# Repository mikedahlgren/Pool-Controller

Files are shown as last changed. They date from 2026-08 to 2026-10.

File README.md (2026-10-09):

# Pool Controller

This runs a pool from a [Waveshare ESP32-S3-RELAY-6CH](https://www.waveshare.com/esp32-s3-relay-6ch.htm) and the PoolVeras sensor hat plugged onto its Pico headers.

The Waveshare board talks to the pump, switches the acid pump and the pool light, and reports its own chip temperature. The hat is where the sensors connect: Atlas probe circuits, a 4-20 mA filter-pressure sender, optional pH current loop, DS18B20 temperature sensors, and dry contacts. Home Assistant and the page at `http://pool-controller.local` show the readings. Once an hour the controller can post pH and water temperature to PoolVeras.

## How the hardware is split

| Job | Board |
|-----|---|
| Pentair IntelliFlo on RS485 | Waveshare, GPIO17 and GPIO18 |
| Acid pump | Waveshare relay CH2, GPIO2 |
| Pool light | Waveshare relay CH6, GPIO46 |
| Waterfall relay | Waveshare relay CH1, GPIO1. Leave it off unless you use it |
| Board temperature | Inside the ESP32-S3. This is the chip, not the pool |
| Atlas pH, ORP, salinity, RTD, or dissolved oxygen | Hat sockets. Any of those boards can go in any pair |
| Filter pressure and other 4-20 mA loops | Hat screw J8. Each loop needs its own 12 V or 24 V supply |
| Air and water temperature | Hat screw J6, DS18B20 sensors, one 4.7k shunt on JP6 |
| Dry contacts | Hat screw J7. A bare switch to the GND screw. ON means closed |

CH3, CH4, and CH5 on the Waveshare are free. The hat's 3.3 V rail, through fuse F1, powers the Atlas boards and the 1-Wire sensors. It does not power the 4-20 mA loops.

Screw order on the hat, left to right, is J3 through J8. Probe returns land on PGND next to PRB, not on the board ground screws.

Connector-by-connector wiring is in [esphome/README.md](esphome/README.md). Acid dosing is in [esphome/ACID_PH.md](esphome/ACID_PH.md). Filter pressure is in [esphome/FILTER_PRESSURE.md](esphome/FILTER_PRESSURE.md). The board files are in [hardware/sensor-hat](hardware/sensor-hat).

## Install

Use ESPHome 2025.9.0 or newer.

From Home Assistant, paste [`esphome/ha-pool-controller.yaml`](esphome/ha-pool-controller.yaml) into ESPHome Builder. It loads the rest of the firmware from the `PoolverasV1` branch. Copy the keys in [`esphome/secrets.yaml.example`](esphome/secrets.yaml.example) into Home Assistant's `secrets.yaml`, then Install.

From a clone of this repo:

```bash
esphome run esphome/pool-controller.yaml
```

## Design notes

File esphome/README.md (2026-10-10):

# Sensor hat

The hat plugs onto the Waveshare Pico headers. Screw connectors run along the edge, left to right: **J3, J4, J5, J6, J7, J8**.

Relays and the pump cable stay on the Waveshare. See [the repo README](../README.md).

## Atlas circuit boards

Three pairs of sockets. The silk says pH, ORP, and EZO so the installer can tell them apart. Any Atlas circuit can go in any pair: pH, ORP, conductivity (salinity), RTD, or dissolved oxygen.

Each circuit uses both sockets in its pair.

- The socket nearer the screws is power: VCC, PRB, PGND.
- The socket farther from the screws is data: GND, TX, RX. Pin 1 of that socket is ground.

The probe cable lands on the two screws under that pair.

| Pair | Screws | Probe screws, left to right |
|---|---|---|
| Labeled pH | J3 | PRB, PGND |
| Labeled ORP | J4 | PRB, PGND |
| Labeled EZO | J5 | PRB, PGND |

PRB is the probe signal. PGND is that probe's return. PGND is not the ground screw on J6 or J7. Leave the probe return on PGND.

Factory boards on the pairs labeled pH and ORP speak UART and answer as soon as they are seated. The device page shows what each socket found: pH Socket, ORP Socket, EZO Socket. Readings show up as EZO pH, ORP, Conductivity, Salinity, TDS, RTD Temperature, or Dissolved Oxygen, based on the board, not the label.

A board that was already switched to I2C still works in any socket. Two of the same type: the reading comes from the first socket that has one, in the order pH label, ORP label, EZO label.

The third pair (labeled EZO) is the I2C bus, shared with J16. J16 is a female 4-pin socket for a 2.42 inch SSD1309. Pin order, from the left: GND, 3V3, SCL, SDA. The screen address is 0x3C. Solder the socket and plug the display in with its GND pin on the left. A factory UART board on that pair will fight the screen, so switch that Atlas board to I2C on one of the other pairs first. Atlas defaults are 99 (pH), 98 (ORP), and 100 (EC).

## pH

Pool pH is the value used for acid dosing and PoolVeras. On the device page, **pH Source** chooses it:

| Setting | What Pool pH uses |
|---|---|
| Auto | The Atlas pH board, if one is answering. Otherwise the 4-20 mA kit. |
| EZO | The Atlas pH board only. |
| 4-20 mA | The industrial kit on J8 screw 2 only. |

`ph_offset` trims only the 4-20 mA reading. Calibrate an Atlas pH board on the module.

Acid dosing behavior is in [ACID_PH.md](ACID_PH.md).

## 4-20 mA (J8)

Left to right: GND, 1, 2, 3, 4.

Each signal screw already has a 150 ohm resistor to the GND screw, plus a filter and a clamp. Do not add another shunt.

These loops need their own DC supply, usually 12 V or 24 V, inside the transmitter's range. Do not power them from the hat's 3.3 V pin.

For each channel:

1. Supply positive to the transmitter positive.
2. Transmitter negative to that channel's signal screw.
3. Supply negative to the GND screw.

One supply can feed all four channels. Split the positive side. Each transmitter returns on its own signal screw.

| Screw | What the firmware does |
|---|---|
| 1 | Filter pressure. GPIO7. Default range 0 to 0.5 MPa. See [FILTER_PRESSURE.md](FILTER_PRESSURE.md). |
| 2 | Industrial pH kit, 4 mA = 0 pH, 20 mA = 14 pH. GPIO8. |
| 3 | Milliamps only. GPIO9. |
| 4 | Milliamps only. GPIO10. |

At 20 mA the 150 ohm resistor is 3.0 V. The ESP32-S3 analog input is soft above about 2.5 V, which is about 16 mA. Normal pool pressure and pH sit under that. The top of the scale reads a little low. The 150 ohm parts stay as they are.

Do not land a fault wire from the Atlas industrial transmitter on the hat. That output is 12 to 24 V.

## 1-Wire (J6)

Left to right: 3V3, DATA, GND. The data pin is GPIO37.

This is for DS18B20 sensors. Air and water can share the three screws. Fit **one** shunt on JP6. Use the 4.7k position for these sensors. The 2.2k and 1k positions are the other choices. Do not fit more than one.

After the first boot, copy each sensor's address from the ESPHome log into `secrets.yaml` as `air_temp_id` and `water_temp_id`.

**Board Temperature** is separate. It is the ESP32-S3 chip, in °F. It rises when WiFi is busy. It is not a stand-in for the air or water sensor.

## Contacts (J7)

Left to right: GND, 1, 2, 3, 4.

Each input is a dry contact: a switch with no voltage of its own. One side goes to a numbered screw. The other side goes to the GND screw on J7. ON means that switch is closed.

| Screw | GPIO |
|---|---|
| 1 | GPIO47 |
| 2 | GPIO16 |
| 3 | GPIO14 |
| 4 | GPIO13 |

Do not connect a powered switch output (5 V, 12 V, or 24 V). The clamp will hold the pin in a safe range and dump the extra current onto the 3.3 V rail.

## Power on the hat

The hat takes 3.3 V from the Waveshare header, through fuse F1 (0.2 A). That rail runs the Atlas circuits, the 1-Wire sensors, and the pull-ups. It does not run 4-20 mA loops.

## Install

Home Assistant: paste [`ha-pool-controller.yaml`](ha-pool-controller.yaml) into ESPHome Builder. It loads the packages from the `PoolverasV1` branch. Add the keys in [`secrets.yaml.example`](secrets.yaml.example) to Home Assistant's `secrets.yaml`, then Install.

From a clone, at the repo root:

```bash
esphome run esphome/pool-controller.yaml
```

The device page is `http://pool-controller.local`.

ESPHome 2025.9.0 or newer. The custom pieces are `pentair_if_ic` (the pump) and `atlas_ezo` (the three sockets).

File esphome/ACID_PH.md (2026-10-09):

# pH probe and Stenner 45M5 acid dosing

For a **50,000 gallon** pool with **31% muriatic acid** and a **Stenner 45M5** (120 V, 1.7 A, #5 tube, **2.5–50 GPD** depending on the dial).

Pool pH can come from an Atlas pH circuit in any socket, or from the industrial 4-20 mA kit on J8 screw 2. **pH Source** on the device page picks which one. Auto uses the circuit board when it answers, and the kit otherwise. Connector map: [README.md](README.md).

The kit is the [Atlas Scientific Industrial pH Kit](https://atlas-scientific.com/kits/industrial-ph-kit/) (KIT-102P): 4 mA is 0 pH, 20 mA is 14 pH. The 150 ohm shunt for that screw is already on the hat. `ph_offset` trims the kit reading only.

Lights stay on **CH6**. Acid uses **CH2**. Do **not** put the Stenner on CH1 — that GPIO still belongs to the unused waterfall switch in `schedule.yaml`. Leave **Waterfall (Auto) OFF** in Home Assistant so CH1 does not chatter.

## Relays on the Waveshare ESP32-S3-RELAY-6CH

| Channel | GPIO | Use |
|---|---|-----|
| CH1 | GPIO1 | Unused (waterfall YAML — leave off) |
| **CH2** | **GPIO2** | **Stenner 45M5 hot** |
| CH6 | GPIO46 | Pool lights (existing) |

## Stenner electrical (CH2)

Switch **only the 120 V hot**. Neutral and ground stay continuous.

```
Panel 120 V hot ──> CH2 COM
CH2 NO ────────────> Stenner black (hot)
Stenner white ─────> Neutral
Stenner green ─────> Ground
```

1.7 A is well under the 10 A relay. Add an **RC snubber** (or MOV) across the Stenner motor leads if the relay pits or Wi‑Fi blips when it clicks — it is an inductive motor.

`restore_mode` is always off. Home Assistant cannot leave the pump on; only a timed pulse script can energize it. A 1-second watchdog force-offs if that fails.

## Plumbing (25 PSI max)

The 45M5 is rated **25 PSI**. Inject into the **return after the filter** (and after a heater if you have one), never into the filter inlet / head-pressure port, and **never into the pH sample loop** (that stream returns to pump suction).

Keep the injection check valve. Prime suction from the acid tank with the pump running using **Acid Prime 10s**.

## Stenner dial

At **100%** the 45M5 is about **4.4 fl oz/min** — too fast to hold on for a 50k pool. Set the mechanical dial to about **20–30%** (~10–15 GPD, ~0.9–1.3 oz/min), then let the ESP pulse.

Default firmware pulse is **10 seconds**, then **15 minutes** settle, max **1200 s (20 min) per calendar day**. Measure actual output with a graduated cylinder (tube wear and dial both matter).

Rough chemistry (31% HCl, 50,000 gal, typical TA): on the order of **tens of ounces** to move pH ~0.2. That is many 10 s pulses over hours, which is the point — no single dump.

## Atlas Industrial pH Kit (KIT-102P)

| In the kit | Role |
|---|---|
| Industrial pH Transmitter (IND-pH) | Isolated **4-wire** transmitter: 9–36 VDC power, **4–20 mA = 0–14 pH**, 35 mm DIN rail, local display and buttons |
| Industrial pH probe | 3/4″ NPT body, ~10 ft cable, double-junction. Order **with PT-1000** so the transmitter can temperature-compensate |
| pH 4 / 7 / 10 pouches + storage pouch | First calibration only; buy bottles for later |

Do **not** wire the glass probe to the ESP32. The transmitter does the high-impedance work; the ESP only reads the 4–20 mA loop.

This is **not** the Yosoo filter-pressure wiring. Yosoo is a 2-wire loop (power and signal are the same pair). Atlas is **4-wire**: power on one pair, isolated 4–20 mA on another.

### Extra parts (not in the kit)

| Item | Notes |
|---|---|
| **Second** 150 Ω 1% metal-film, ≥0.25 W | Dedicated shunt. Do not share the filter-pressure resistor. **Not 250 Ω** (20 mA × 250 Ω = 5 V, above the ESP32 ADC). |
| 35 mm DIN-rail snippet | Transmitter is DIN-rail only and is **not** weatherproof. Mount it dry next to the Waveshare board. |
| 1″ × 3/4″ FNPT tee (or 1″ tee + 3/4″ bushing) | Probe is 3/4″ NPT. Atlas’s cheap lab “probe pipe fitting” is the wrong body. |
| Isolation ball valves on the sample loop | Close them **full of water** for calibration or to keep the glass wet. |
| PTFE tape | 3/4″ NPT into the tee. Keep tape off the flat sensing face. |

Board **VIN must be 12–24 V DC** (same supply as the Yosoo). USB 5 V will not run this transmitter (it needs 9–36 V). Atlas minimum is 9 V; 12 V is the practical floor with the pressure loop.

### Probe plumbing (1″ sample loop)

Reuse the old discharge-to-suction 1″ PVC cell:

- Takeoff **after the pump**, return **before the pump**. After-filter takeoff is cleaner if the piping can move; after the CircuPool cell is worse (gas / high chlorine on the glass).
- Probe in a **1″ × 3/4″ FNPT** tee. Water should sweep the flat face (slight angle or vertical). Not upside down (gel void). Not in a dead-end trap.
- Keep the cell a **low wet pocket** so it cannot drain when the IntelliFlo stops. A light check on the suction return is optional; a U-bend is more reliable than stiff spring checks (those can stall at Speed 1).
- Leave sample valves **open** in normal use. RPM interlocks prove the IntelliFlo is running, not that this bypass is open.
- If you blow the lines for winter, **pull the probe** into storage solution.

### Transmitter terminals

Connect only **power**, **pH probe**, **PT-1000** (if present), and **4–20 mA**. Leave the rest disconnected.

| Terminal | Connect to | Notes |
|---|---|---|
| **PWR + / PWR −** (larger keyed plug, 9–36 V) | Board **VIN+** / **VIN−** | Separate from the 4–20 mA pair |
| **pH** (two wires) | Probe pH pair | Reverse does not damage the probe; readings will be wrong |
| **TEMP** (two wires) | Probe PT-1000 | No polarity |
| **4–20 mA + / −** | J8 screw 2 and the GND screw | Isolated current. 4 mA = 0 pH, 20 mA = 14 pH. The shunt is on the hat. |
| **F** (fault) | **Nothing** | Outputs **12–24 V** (same as PWR). Will destroy an ESP GPIO |
| **4 / 7 / 10** (PLC cal) | **Nothing** | Optional PLC strobes; calibrate with the buttons instead |

### 4-20 mA wiring (J8 screw 2)

Power the transmitter from 12 V or 24 V, not from the hat's 3.3 V. Filter pressure, if you use it, takes J8 screw 1. Do not share the two signal screws.

```
Supply +  ---- transmitter PWR +
Supply -  ---- transmitter PWR -  and J8 GND

transmitter 4-20 mA +  ---- J8 screw 2
transmitter 4-20 mA -  ---- J8 GND
```

At 150 ohm: 4 mA is 0.60 V (pH 0), 12 mA is 1.80 V (pH 7), 20 mA is 3.00 V (pH 14). The analog input is soft above about 2.5 V, so a reading near 14 pH can sit a little low. Normal pool pH does not.

ESP32 ADC max is about 3.1 V at 12 dB attenuation, so 3.00 V at pH 14 is intentional headroom. **pH Loop Current** and **pH Loop Voltage** on the device page are the diagnostics.

Below ~3.5 mA or above ~21 mA the firmware publishes `Pool pH` as unknown (open wire / short) and **Acid Interlock** shows a probe fault.

### Substitutions (`ha-pool-controller.yaml` / `pool-controller.yaml`)

These values are for KIT-102P. Do not change the pH scale unless you replace the transmitter.

```yaml
acid_pump_pin: GPIO2
ph_sensor_pin: GPIO8
ph_shunt_ohms: "150.0"
ph_scale_low: "0"
ph_scale_high: "14"
ph_offset: "0.2"    # added to the 4–20 mA scale so ESP/HA match the Atlas display
ph_update_interval: "5s"  # Pool pH, loop voltage, and loop current
acid_pump_gpd: "25"       # Stenner GPD at dial 10 (this install is a 25 GPD pump)
```

### Calibrate on the transmitter, then trim the loop

The ESP does not store pH calibration. Buffers are done **on the Atlas** (display / buttons). **CAL 7 first** — that resets stored points; then 4 and 10.

1. Probe in pH 7. Hold the **orange** button ~1.5 s (`CAL7` → `donE`).
2. Rinse, pH 4, **red** button. Optional pH 10, **blue** button.
3. Trim 4–20 mA so Home Assistant matches: hold **red + blue** ~1.5 s. Adjust 20 mA until **Pool pH** just hits 14.000, save; then 4 mA until 0.000. Use **pH Loop Current** as a check (pH 7 buffer → 12.00 mA).
4. If the ESP page / Home Assistant still sit a fixed amount away from the Atlas display (ADC and shunt error), set `ph_offset` in `ha-pool-controller.yaml` (default `0.2`, added to the 4–20 mA value) and reflash. Do not change `ph_scale_low` / `ph_scale_high`.

A two-point 7 then 4 is enough for a pool. The kit pouches are one first cal; keep bottles of 7 and 4 on the pad.

## Interlocks (auto and Acid Pulse)

All must pass:

- IntelliFlo running and RPM ≥ **Acid Min Pump RPM** (default 1200)
- pH between **6.8 and 8.6** (probe in water, not failed)
- pH not already below **7.1**
- Today’s runtime under **Acid Max Seconds Today**
- After a pulse, wait **Acid Settle Minutes**

**Acid Auto Dose** uses hysteresis: a correction starts when pH ≥ **Acid pH Start** (default 7.6) and keeps pulsing until pH ≤ **Acid pH Target** (7.4). Auto does **not** come back on after a reboot — you have to enable it again.

**Acid Prime 10s** only requires the circulation pump at min RPM (for filling tubing).

Until the pH loop reads ~4–20 mA, **Acid Interlock** is not `OK` and auto-dose will not run.

## First-week checkout

1. Wire CH2 and confirm **Acid Prime** with a bucket on the discharge (pump on, auto **off**).
2. Power the Atlas from VIN (display on). Confirm **pH Loop Current** is in the 4–20 mA range with the probe in water.
3. Calibrate 7 then 4 on the transmitter; confirm Home Assistant **Pool pH** against the buffers, then a Taylor test of the pool.
4. Leave **Acid Auto Dose off**. Use one **Acid Pulse** and watch pH over 30+ minutes.
5. Enable auto only after a pulse matches a Taylor/FAS-DPD sanity check.

Turn auto **off** when vacuuming, backwashing, or working on the pad.

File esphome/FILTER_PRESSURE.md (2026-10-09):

# Filter tank head-pressure sensor

This adds filter-tank pressure measurement to the Waveshare **ESP32-S3-RELAY-6CH** using a 2-wire **4–20 mA** transmitter such as:

[Yosoo Silicon Pressure Transmitter, 4–20 mA, G1/4, 0–0.5 MPa (ASIN B07NQ36XTC)](https://www.amazon.com/gp/product/B07NQ36XTC)

The IntelliFlo `Pressure` entity already in Home Assistant is the **pump’s internal reading** (bar). This package is a separate gauge on the **filter tank** so you can see when the cartridge/sand needs cleaning.

## Sensor specs (this listing)

| Item | Value |
|---|---|
| Output | 4–20 mA (loop-powered, typically 2-wire) |
| Range | 0–0.5 MPa (0–5 bar, **0–72.5 psi**) |
| Supply | **8–32 V DC** (do not power from 5 V USB or 3.3 V) |
| Thread | **G1/4** (BSPP, not NPT) |
| Media | Water, air, oil (stainless body) |

Pool sand/cartridge filters usually run in the **8–25 psi** range, so 0–0.5 MPa is a good fit.

The hat already has the 150 ohm shunt, the filter capacitor, and the clamp. Connector map: [README.md](README.md).

## Wiring

J8, left to right: GND, 1, 2, 3, 4. Filter pressure is screw 1 (GPIO7).

Use a separate 12 V or 24 V supply. Do not use the hat's 3.3 V, and do not use the RS485 ground.

```
Supply +  ---- transmitter +
Transmitter - ---- J8 screw 1
Supply -  ---- J8 GND screw
```

A 3-wire unit uses the same GND screw for its ground wire, and screw 1 for the signal.

At 150 ohm: 4 mA is 0.60 V (0 psi), 12 mA is 1.80 V, 20 mA is 3.00 V (72.5 psi). The analog input is soft above about 2.5 V, so the top of the scale reads a little low. Normal filter pressure sits under that.

Plumbing parts that are not on the hat: a G1/4 to 1/4 inch NPT adapter if the filter port is NPT, a tee if you want to keep the mechanical gauge, and PTFE tape. The Yosoo thread is G1/4.

## Plumbing

1. Kill power to the pump. Isolate and depressurize the filter (open the air relief / drain as your filter manual describes).
2. Remove the mechanical gauge, or install a **tee** so the gauge stays.
3. Fit the G1/4 → NPT adapter if needed. Do not crank a stainless G1/4 sensor hard into a plastic NPT port.
4. Mount the transmitter **upright** if the body has a cable gland, with the cable dripping down so water does not run into the connector.
5. Restart the pump and check for leaks **before** sealing the electrical box.

## Firmware substitutions

In `esphome/pool-controller.yaml`:

```yaml
substitutions:
  filter_pressure_pin: GPIO7
  filter_pressure_shunt_ohms: "150.0"
  filter_pressure_full_scale_mpa: "0.5"
```

If you bought a different Yosoo range (0–0.2 / 1.0 / 1.6 MPa), change `filter_pressure_full_scale_mpa` to match the label on the sensor.

If you use a different shunt (120 Ω is also safe), set `filter_pressure_shunt_ohms` to that value. Stay at or below **150 Ω** so 20 mA cannot exceed ~3.1 V.

## Entities

| Entity | Purpose |
|---|---|
| **Filter Tank Pressure** | Head pressure in psi |
| **Filter Tank Pressure Bar** | Same reading in bar (compare to IntelliFlo pressure) |
| **Filter Loop Current** | Diagnostic mA; ~4 mA at rest, ~8–16 mA while the pump is on |
| **Filter Pressure Voltage** | Raw ADC volts |
| **Filter Clean Speed 1–4** | Learned (or manually set) clean-filter psi at that speed. 0 = not learned yet |
| **Filter Est Speed 1–4** | Effective clean psi: learned value if present, otherwise estimated from other speeds |
| **Filter Clean Baseline** | Clean psi used right now |
| **Filter Pressure Over Clean** | Current psi minus baseline. Backwash when this reaches **Filter Pressure Rise** |
| **Filter Pressure Rise** | Trip delta (default **10 psi**, Pentair Triton II) |
| **Filter Learn Hours** | How long a speed must run before a baseline is learned (default **2**, max 48) |
| **Filter Learn Time** | Hours of Speed 1–4 runtime collected toward the current learn window |
| **Filter Needs Backwash** | Problem binary sensor (stays on after the pump stops) |
| **Filter Backwash Detail** | Why it is or is not calling for a backwash |
| **Filter Pressure Fault** | Loop &lt; 3.5 mA (open) or &gt; 21 mA (short) |
| **Save Clean Filter Pressure** | Optional: store the current reading now instead of waiting to learn |
| **Reset Filter Baselines** | Clear learned values and start over (sand change, etc.) |

Pentair’s Triton II TR140 manual: backwash at **+10 psi** over the clean reading. Leave rise at 10.

### How baselines are learned

You do **not** have to press Save. Example: Speed 1 at 1500 RPM, lowest 2-hour average is 8 psi → **Filter Clean Speed 1** becomes 8 psi → trip at **18 psi**.

The firmware:

1. Ignores the first 10 minutes after the IntelliFlo starts (air purge / prime).
2. While RPM is within ~200 of Speed 1–4, records 5-minute averages.
3. After **Filter Learn Hours** of that speed’s runtime (default 2, not necessarily one continuous wall-clock block), takes the **lowest** N-hour average seen.
4. Only **lowers** a baseline after that (a dirty week cannot raise the clean number). After a backwash, a lower stretch updates it.
5. Speeds you have not run yet are estimated from the ones you have (`head ≈ a + b·RPM²`).

Set **Filter Learn Hours** to 4 or 8 if you want a longer, more conservative window. Save is still there if you just backwashed and do not want to wait. **Reset Filter Baselines** after new sand.

The backwash flag only **updates** while the pump is running near a known speed. If it trips, it **stays on** after the pump shuts off so Home Assistant can still notify you at night.

## Checkout

1. Power the Waveshare board from **12–24 V** on the VIN screw terminal (not USB alone).
2. With the transmitter disconnected, Filter Loop Current should drop and **Filter Pressure Fault** should turn on.
3. With the transmitter connected and the pump **off**, expect roughly **4 mA / ~0 psi** (plus a little gauge offset).
4. Start the pump; pressure should rise into the same ballpark as the mechanical gauge (often within 1–2 psi; cheap transmitters are about ±1.5% FS).
5. If the reading is stuck near 0 or the fault stays on, swap red/black — a reversed 2-wire loop reads as an open circuit.

## Home Assistant

After the ESPHome API reconnects you should see `sensor.filter_tank_pressure` and `binary_sensor.filter_needs_backwash` (`device_class: problem`). A simple notify:

```yaml
automation:
  - alias: Pool filter needs backwash
    trigger:
      - platform: state
        entity_id: binary_sensor.pool_controller_filter_needs_backwash
        to: "on"
    action:
      - service: notify.mobile_app_your_phone
        data:
          title: Pool filter
          message: "TR140 is about +10 psi over clean. Time to backwash."
```

Replace the entity_id and notify target with the names Home Assistant actually assigned. You can also put **Filter Needs Backwash** on a dashboard badge and skip the automation until you want a push.

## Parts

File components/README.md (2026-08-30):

# ESPHome Components

## [pentair_if_ic](pentair_if_ic/README.md)

Controls a Pentair IntelliFlo variable-speed pump over RS485, and optionally a Pentair IntelliChlor on the same bus.

- Shared RS485 with bus arbitration
- Pump sensors and controls for Home Assistant
- IntelliChlor package is optional (`esphome/Include/chlorinator.yaml`); this install uses a CircuPool cell that does not speak that protocol

Home Assistant ESPHome Builder loads this from GitHub via `esphome/ha-pool-controller.yaml`. A local CLI compile uses `external_components` in `esphome/pool-controller.yaml`.

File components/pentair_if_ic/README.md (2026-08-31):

# Pentair IntelliFlo + IntelliChlor Component

ESPHome component for controlling Pentair IntelliFlo variable speed pumps and IntelliChlor salt water chlorinators over RS485.
This component is a combination of two other components:
1. [Nicostrown's Pentair Intelliflo Component](https://github.com/nicostrown/ESPHome-Pentair-Intelliflo) with a fix to the RPM setting protocal and adding mor information from the staus request.
2. [Scott Wolf's (wolfson292) Pentair Intellichlor component](https://github.com/wolfson292/intellichlor)

The major change is they both use the same in and out buffers, so the pump and clorinator can communicate on a common RS485 bus.

## Features

- **Unified Communication**: Single component manages both IntelliFlo pump and IntelliChlor chlorinator on shared RS485 bus
- **Automatic Polling**: Configurable polling intervals (default 30s)
- **Bus Arbitration**: Prevents transmission collisions between protocols
- **Full Sensor Support**: Exposes all known pump and chlorinator sensors to Home Assistant
- **Manual Refresh**: On-demand chlorinator status updates via button/automation

## Hardware Requirements

- ESP32 or ESP8266
- RS485 to TTL converter (e.g., MAX485) if not part of your board
- Pentair IntelliFlo pump
- Pentair IntelliChlor chlorinator
- Optional: Flow control pin for half-duplex RS485

## Installation

Add to your ESPHome configuration:

```yaml
external_components:
  - source: components/Pool_Automation/components
    components: [pentair_if_ic]
    refresh: 0s

uart:
  - id: uart_bus
    tx_pin: GPIO17
    rx_pin: GPIO16
    baud_rate: 9600

pentair_if_ic:
  id: my_pentair
  uart_id: uart_bus
  update_interval: 30s
  # Optional: poll IntelliChlor on this bus (default true). CircuPool / no SWG: false
  # enable_intellichlor: false
  # Optional: flow_control_pin for RS485 direction control
  # flow_control_pin: GPIO4
```

## Configuration Variables

### Platform Configuration

- **id** (*Required*, ID): Unique ID for the component instance
- **uart_id** (*Required*, ID): ID of the UART bus
- **update_interval** (*Optional*, Time): Polling interval (default: 30s)
- **enable_intellichlor** (*Optional*, boolean): Queue IntelliChlor commands on the shared RS485 bus (default: `true`). Set `false` if the only device on the bus is an IntelliFlo (this install: CircuPool RJ-60 PLUS).
- **flow_control_pin** (*Optional*, Pin): GPIO pin for RS485 direction control

### IntelliFlo Pump Sensors

```yaml
sensor:
  - platform: pentair_if_ic
    power:
      name: "Pump Power"
      id: pump_power
      unit_of_measurement: "W"
    rpm:
      name: "Pump RPM"
      id: pump_rpm
      unit_of_measurement: "RPM"
    flow:
      name: "Pump Flow Rate"
      id: pump_flow
      unit_of_measurement: "GPM"
    pressure:
      name: "Pump Pressure"
      id: pump_pressure
      unit_of_measurement: "PSI"
    time_remaining:
      name: "Program Time Remaining"
      id: time_remaining
      unit_of_measurement: "min"
    clock:
      name: "Pump Clock"
      id: pump_clock
      unit_of_measurement: "min"

binary_sensor:
  - platform: pentair_if_ic
    running:
      name: "Pump Running"
      id: pump_running

text_sensor:
  - platform: pentair_if_ic
    program:
      name: "Active Program"
      id: active_program
```

### IntelliChlor Sensors

```yaml
sensor:
  - platform: pentair_if_ic
    salt_ppm:
      name: "Salt Level"
      id: salt_ppm
      unit_of_measurement: "PPM"
    water_temp:
      name: "Water Temperature"
      id: water_temp
      unit_of_measurement: "°F"
    status:
      name: "Chlorinator Status"
      id: chlorinator_status
    error:
      name: "Chlorinator Error"
      id: chlorinator_error
    set_percent:
      name: "Chlorinator Output %"
      id: chlorinator_set_percent
      unit_of_measurement: "%"

binary_sensor:
  - platform: pentair_if_ic
    no_flow:
      name: "No Flow Alarm"
    low_salt:
      name: "Low Salt Alarm"
    high_salt:
      name: "High Salt Alarm"
    clean:
      name: "Clean Cell Required"
    high_current:
      name: "High Current Alarm"
    low_volts:
      name: "Low Voltage Alarm"
    low_temp:
      name: "Low Temperature Alarm"
    check_pcb:
      name: "Check PCB"

text_sensor:
  - platform: pentair_if_ic
    version:
      name: "Chlorinator Version"
      id: chlorinator_version

number:
  - platform: pentair_if_ic
    swg_percent:
      name: "Chlorine Output"
      id: swg_percent_number
      min_value: 0
      max_value: 100
      step: 1

switch:
  - platform: pentair_if_ic
    takeover_mode:
      name: "Takeover Mode"
      id: takeover_mode_switch
```

## Available Functions

Call these functions from Lambda actions or automations:

### Pump Control Functions

```cpp
// Request current pump status
id(my_pentair).requestPumpStatus();

// Start/stop pump
id(my_pentair).run();
id(my_pentair).stop();

// Set pump to specific RPM
id(my_pentair).commandRPM(1450);  // RPM value

// Set pump to specific flow rate
id(my_pentair).commandFlow(45);  // Flow in GPM * 10

// Run local program (1-4)
id(my_pentair).commandLocalProgram(0);  // Program 1
id(my_pentair).commandLocalProgram(1);  // Program 2

// Run external program (1-4)
id(my_pentair).commandExternalProgram(0);  // External Program 1

// Save RPM value to program slot
id(my_pentair).saveValueForProgram(0, 1450);  // Program 1, 1450 RPM

// Control modes
id(my_pentair).pumpToLocalControl();
id(my_pentair).pumpToRemoteControl();

// Set pump clock (NOTE: Not supported on most IntelliFlo models)
// Most pumps return error 0xFF 0x19 - clock is read-only
// Clock must be set via pump's physical keypad on most models
id(my_pentair).setPumpClock(14, 30);  // Set to 14:30 (2:30 PM)
```

### Chlorinator Control Functions

```cpp
// Refresh chlorinator status (bypasses rate limiting)
id(my_pentair).refresh_chlorinator();

// Standard refresh (respects 25s rate limit)
id(my_pentair).read_all_chlorinator_info();

// Legacy alias
id(my_pentair).read_all_info();
```

## Example Configurations

### Complete Pool Controller

```yaml
external_components:
  - source: components/Pool_Automation/components
    components: [pentair_if_ic]
    refresh: 0s

uart:
  - id: uart_bus
    tx_pin: GPIO17
    rx_pin: GPIO16
    baud_rate: 9600

pentair_if_ic:
  id: my_pentair
  uart_id: uart_bus
  update_interval: 30s

sensor:
  - platform: pentair_if_ic
    power:
      name: "Pool Pump Power"
    rpm:
      name: "Pool Pump RPM"
    salt_ppm:
      name: "Pool Salt Level"
    water_temp:
      name: "Pool Water Temperature"

number:
  - platform: pentair_if_ic
    swg_percent:
      name: "Chlorine Output"
      id: chlorine_output

switch:
  - platform: pentair_if_ic
    takeover_mode:
      name: "Chlorinator Takeover Mode"

button:
  - platform: template
    name: "Refresh Chlorinator"
    on_press:
      - lambda: |-
          id(my_pentair).refresh_chlorinator();

  - platform: template
    name: "Run Pump at 1450 RPM"
    on_press:
      - lambda: |-
          id(my_pentair).commandRPM(1450);
          
  - platform: template
    name: "Stop Pump"
    on_press:
      - lambda: |-
          id(my_pentair).stop();
```

### Automation Example

```yaml
# Adjust chlorine output based on temperature
automation:
  - interval: 5min
    then:
      - lambda: |-
          float temp = id(water_temp).state;
          if (temp > 85.0) {
            id(chlorine_output).set_value(80);  // Increase output
          } else if (temp < 75.0) {
            id(chlorine_output).set_value(40);  // Decrease output
          }
          
# Run pump program on schedule
time:
  - platform: homeassistant
    on_time:
      - seconds: 0
        minutes: 0
        hours: 8
        then:
          - lambda: |-
              id(my_pentair).commandLocalProgram(0);  // Run Program 1
              
      - seconds: 0
        minutes: 0
        hours: 20
        then:
          - lambda: |-
              id(my_pentair).stop();
```

### Manual Control Buttons

```yaml
button:
  - platform: template
    name: "Low Speed (1450 RPM)"
    on_press:
      - lambda: id(my_pentair).commandRPM(1450);
      
  - platform: template
    name: "Medium Speed (2350 RPM)"
    on_press:
      - lambda: id(my_pentair).commandRPM(2350);
      
  - platform: template
    name: "High Speed (3110 RPM)"
    on_press:
      - lambda: id(my_pentair).commandRPM(3110);
      
  - platform: template
    name: "Priming Speed"
    on_press:
      - lambda: id(my_pentair).commandRPM(3450);
```

## Troubleshooting

### No Communication

- Verify RS485 wiring (A to A, B to B)
- Check UART baud rate is 9600
- Ensure proper RS485 termination resistors
- Verify TX/RX pins are correct

### Checksum Errors

```
[W][pentair_if_ic]: IF CHECKSUM MISMATCH
```

- Usually indicates bus collisions
- Component includes automatic bus arbitration
- Ensure only one device on the bus is controlling the pump/chlorinator

### Buffer Overflow

```
[W][pentair_if_ic]: IC Buffer overflow
```

- Indicates packet corruption
- Check for electrical noise on RS485 lines
- Verify ground connections
- Consider adding line filters

### IC No Response

```
[E][pentair_if_ic]: IC No response 3 > 4 removing from send queue
```

The driver polls IntelliChlor even when `chlorinator.yaml` is not included. CircuPool and other non-Pentair SWGs will never answer.

- Set `enable_intellichlor: false` on `pentair_if_ic` (this install does that in `schedule.yaml`)
- If you do have an IntelliChlor: check power and RS485, then `id(my_pentair).refresh_chlorinator()`

### Clock Setting Not Supported

```
[W][pentair_if_ic]: IF Setting pump clock - NOTE: Many IntelliFlo models don't support clock setting via RS485
[I][pentair_if_ic]: IF Package received: A5.00.10.60.FF.01.19.02.2E
```

- Most IntelliFlo models don't support setting the clock via RS485
- Error response `0xFF 0x19` indicates command not implemented in pump firmware
- Clock can be read from pump status but cannot be set remotely
- Use pump's physical keypad to set the clock manually
- The `setPumpClock()` function is provided for models that do support it, but will fail on most pumps

## Protocol Details

### IntelliFlo Protocol
- Baud Rate: 9600
- Packet Format: `FF 00 FF A5 ...`
- Checksum: 16-bit sum

### IntelliChlor Protocol
- Baud Rate: 9600
- Packet Format: `10 02 ... 10 03`
- Checksum: 8-bit CRC

### Bus Arbitration
- 150ms minimum gap between transmissions
- 100ms quiet time before transmitting
- Separate queues for IntelliFlo and IntelliChlor packets

## Version History

- **v1.0**: Initial release with unified IntelliFlo + IntelliChlor support
- Support for shared RS485 bus with automatic arbitration
- Configurable polling intervals
- Manual refresh capability

## License

This component is provided as-is for use with ESPHome and Home Assistant.

## Credits

Based on original separate components:
- Pentair IntelliFlo component (https://github.com/nicostrown/ESPHome-Pentair-Intelliflo)
- Pentair IntelliChlor component (https://github.com/wolfson292/intellichlor)

Combined and enhanced for shared RS485 bus operation.

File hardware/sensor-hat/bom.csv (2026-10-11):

Ref | Value | Footprint | LCSC
J1 | Pin socket 1x20 back side | Connector_PinSocket_2.54mm:PinSocket_1x20_P2.54mm_Vertical
J2 | Pin socket 1x20 back side | Connector_PinSocket_2.54mm:PinSocket_1x20_P2.54mm_Vertical
F1 | 0.2A | Fuse:Fuse_1812_4532Metric
C3 | 100nF | PCM_JLCPCB:C_0805 | C28233
R5 | 1k | PCM_JLCPCB:R_0805 | C17513
C4 | 100nF | PCM_JLCPCB:C_0805 | C28233
D1 | BAT54S | Package_TO_SOT_SMD:SOT-23 | C7420333
R1 | 150 | PCM_JLCPCB:R_0805 | C17471
R6 | 1k | PCM_JLCPCB:R_0805 | C17513
C5 | 100nF | PCM_JLCPCB:C_0805 | C28233
D2 | BAT54S | Package_TO_SOT_SMD:SOT-23 | C7420333
R2 | 150 | PCM_JLCPCB:R_0805 | C17471
R7 | 1k | PCM_JLCPCB:R_0805 | C17513
C6 | 100nF | PCM_JLCPCB:C_0805 | C28233
D3 | BAT54S | Package_TO_SOT_SMD:SOT-23 | C7420333
R3 | 150 | PCM_JLCPCB:R_0805 | C17471
R8 | 1k | PCM_JLCPCB:R_0805 | C17513
C7 | 100nF | PCM_JLCPCB:C_0805 | C28233
D4 | BAT54S | Package_TO_SOT_SMD:SOT-23 | C7420333
R4 | 150 | PCM_JLCPCB:R_0805 | C17471
J8 | 4-20 mA | TerminalBlock_Phoenix:TerminalBlock_Phoenix_MKDS-1 | 5_5-5.08_1x05_P5.08mm_Horizontal
R9 | 1k | PCM_JLCPCB:R_0805 | C17513
C8 | 100nF | PCM_JLCPCB:C_0805 | C28233
D5 | BAT54S | Package_TO_SOT_SMD:SOT-23 | C7420333
R13 | 10k | PCM_JLCPCB:R_0805 | C17414
R10 | 1k | PCM_JLCPCB:R_0805 | C17513
C9 | 100nF | PCM_JLCPCB:C_0805 | C28233
D6 | BAT54S | Package_TO_SOT_SMD:SOT-23 | C7420333
R14 | 10k | PCM_JLCPCB:R_0805 | C17414
R11 | 1k | PCM_JLCPCB:R_0805 | C17513
C10 | 100nF | PCM_JLCPCB:C_0805 | C28233
D7 | BAT54S | Package_TO_SOT_SMD:SOT-23 | C7420333
R15 | 10k | PCM_JLCPCB:R_0805 | C17414
R12 | 1k | PCM_JLCPCB:R_0805 | C17513
C11 | 100nF | PCM_JLCPCB:C_0805 | C28233
D8 | BAT54S | Package_TO_SOT_SMD:SOT-23 | C7420333
R16 | 10k | PCM_JLCPCB:R_0805 | C17414
J7 | Contacts | TerminalBlock_Phoenix:TerminalBlock_Phoenix_MKDS-1 | 5_5-5.08_1x05_P5.08mm_Horizontal
R21 | 100 | PCM_JLCPCB:R_0805 | C17408
J6 | 1-Wire | TerminalBlock_Phoenix:TerminalBlock_Phoenix_MKDS-1 | 5_3-5.08_1x03_P5.08mm_Horizontal
JP6 | fit one | Connector_PinHeader_2.54mm:PinHeader_2x03_P2.54mm_Vertical
R24 | 4.7k | PCM_JLCPCB:R_0805 | C17673
R25 | 2.2k | PCM_JLCPCB:R_0805 | C17520
R26 | 1k | PCM_JLCPCB:R_0805 | C17513
R17 | 100 | PCM_JLCPCB:R_0805 | C17408
R18 | 100 | PCM_JLCPCB:R_0805 | C17408
J11 | data socket | Connector_PinSocket_2.54mm:PinSocket_1x03_P2.54mm_Vertical
J12 | probe socket | Connector_PinSocket_2.54mm:PinSocket_1x03_P2.54mm_Vertical
J3 | EZO pH probe | TerminalBlock_Phoenix:TerminalBlock_Phoenix_MKDS-1 | 5_2-5.08_1x02_P5.08mm_Horizontal
R19 | 100 | PCM_JLCPCB:R_0805 | C17408
R20 | 100 | PCM_JLCPCB:R_0805 | C17408
J9 | data socket | Connector_PinSocket_2.54mm:PinSocket_1x03_P2.54mm_Vertical
J10 | probe socket | Connector_PinSocket_2.54mm:PinSocket_1x03_P2.54mm_Vertical
J4 | EZO ORP probe | TerminalBlock_Phoenix:TerminalBlock_Phoenix_MKDS-1 | 5_2-5.08_1x02_P5.08mm_Horizontal
R28 | 4.7k | PCM_JLCPCB:R_0805 | C17673
R27 | 4.7k | PCM_JLCPCB:R_0805 | C17673
J16 | I2C | Connector_PinSocket_2.54mm:PinSocket_1x04_P2.54mm_Vertical
J13 | data socket | Connector_PinSocket_2.54mm:PinSocket_1x03_P2.54mm_Vertical
J14 | probe socket | Connector_PinSocket_2.54mm:PinSocket_1x03_P2.54mm_Vertical
J5 | EZO I2C probe | TerminalBlock_Phoenix:TerminalBlock_Phoenix_MKDS-1 | 5_2-5.08_1x02_P5.08mm_Horizontal
R29 | 10k | PCM_JLCPCB:R_0805 | C17414
SW1 | TS-1187A | Button_Switch_SMD:SW_Push_1P1T_XKB_TS-1187A
R30 | 10k | PCM_JLCPCB:R_0805 | C17414
SW2 | TS-1187A | Button_Switch_SMD:SW_Push_1P1T_XKB_TS-1187A
J17 | external | Connector_PinHeader_2.54mm:PinHeader_1x04_P2.54mm_Vertical

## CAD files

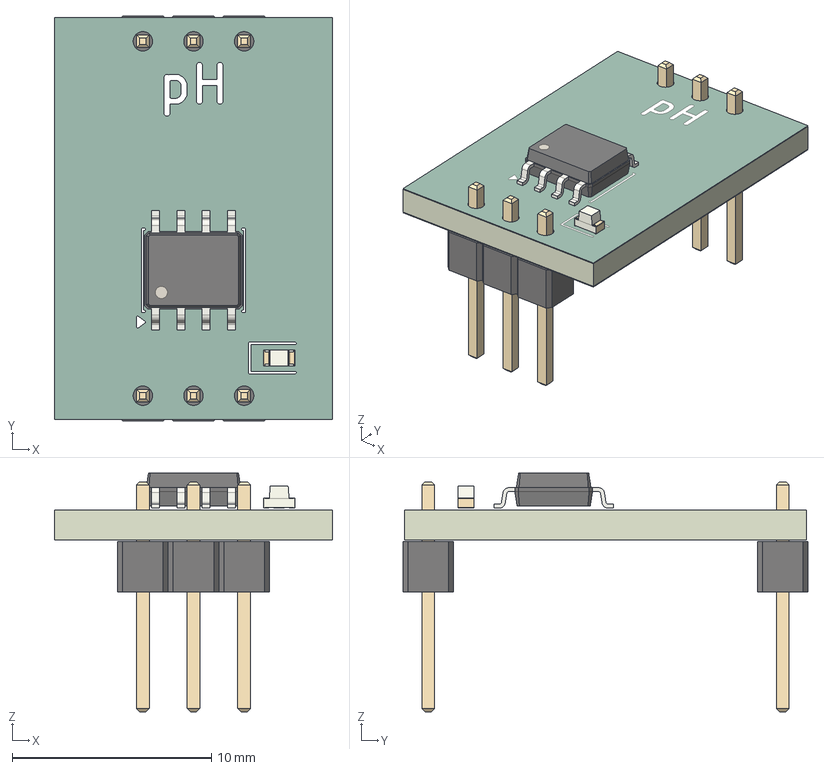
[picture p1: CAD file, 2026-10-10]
hardware/sensor-hat/3d/Atlas_EZO_pH.step
14.0 x 20.3 x 12.0 mm
SOIC-8_3.9x4.9mm_P1.27mm
LED_0603_1608Metric
PinHeader_1x03_P254mm_Vertical x 2
pH_silkscreen x 2
pH_soldermask x 2
pH_PCB

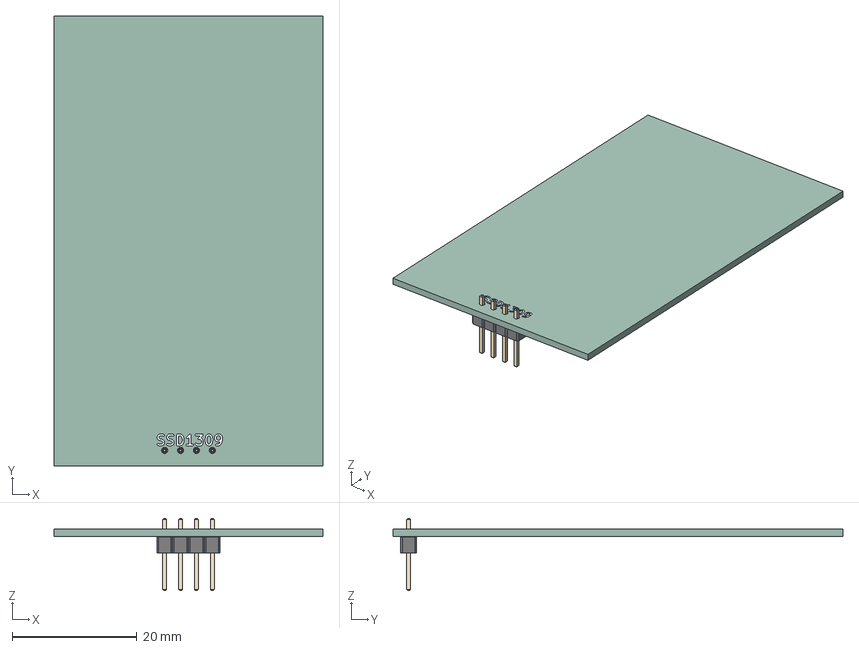
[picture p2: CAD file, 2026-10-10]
hardware/sensor-hat/3d/SSD1309.step
43.0 x 72.0 x 11.5 mm
PinHeader_1x04_P254mm_Vertical
pcb_silkscreen x 2
pcb_PCB

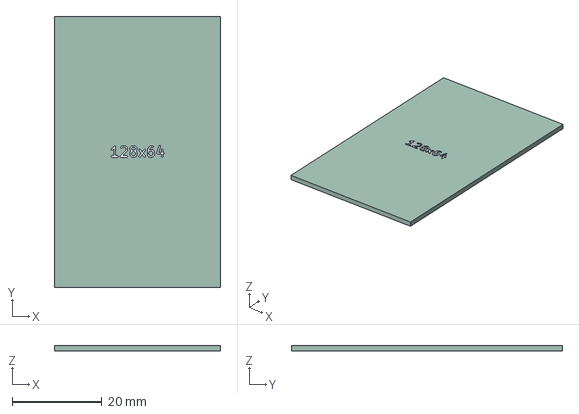
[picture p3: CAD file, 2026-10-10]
hardware/sensor-hat/3d/SSD1309_glass.step
37.0 x 60.5 x 1.27 mm
glass_silkscreen
glass_PCB

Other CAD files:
hardware/sensor-hat/3d/Atlas_EZO_EZO.step
hardware/sensor-hat/3d/Atlas_EZO_ORP.step

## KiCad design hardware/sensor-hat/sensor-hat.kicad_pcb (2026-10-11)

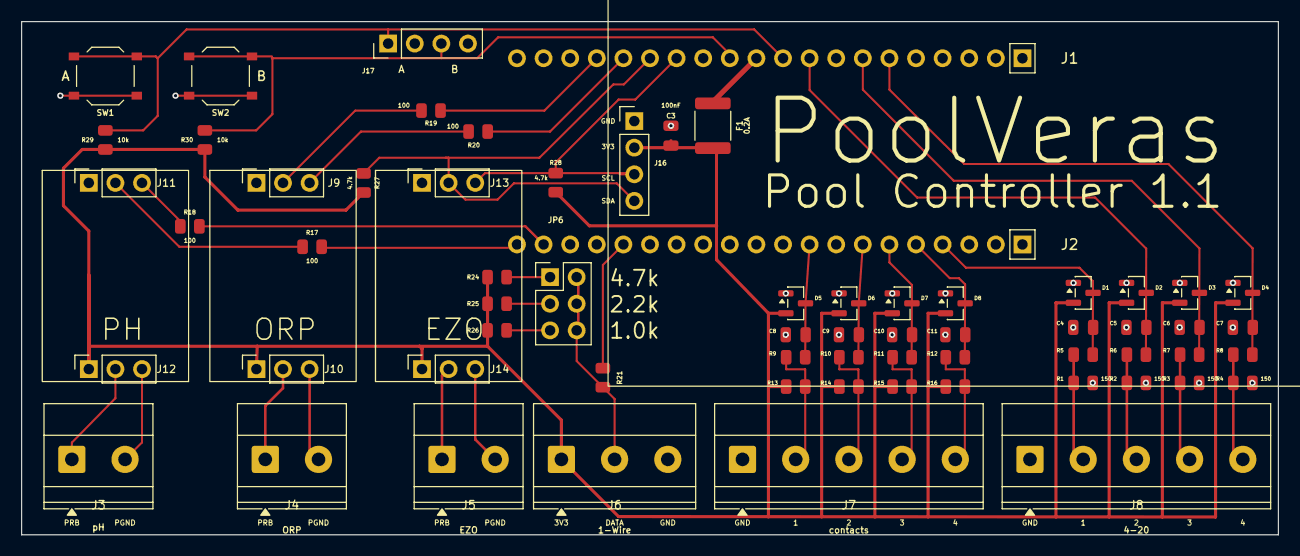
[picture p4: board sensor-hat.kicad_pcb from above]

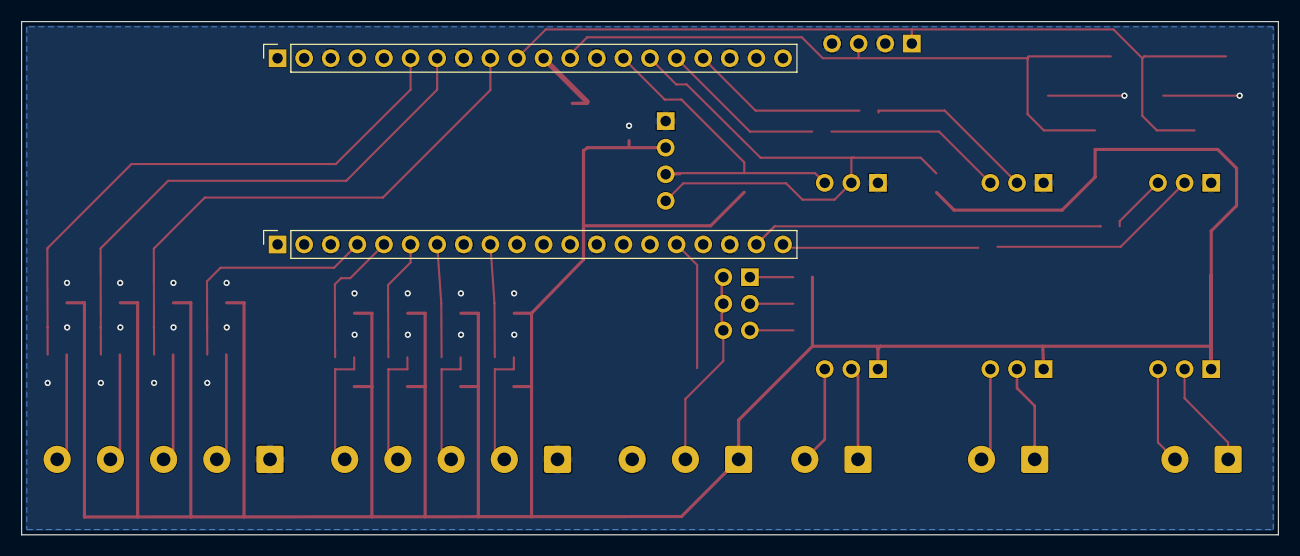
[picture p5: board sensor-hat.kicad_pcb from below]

Board: 2 copper layers, 120.0 x 49.0 mm, 69 parts (2 on the bottom side), 42 nets.

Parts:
C3, C4, C5, C6, C7, C8, C9, C10, C11: 100nF; C_0805
D1, D2, D3, D4, D5, D6, D7, D8: BAT54S; SOT-23
DISP1: SSD1309
EZO1: pH; Atlas_EZO
EZO2: ORP; Atlas_EZO
EZO3: EZO; Atlas_EZO
F1: 0.2A; Fuse_1812_4532Metric
J1, J2: 1x20 socket, bottom; PinSocket_1x20_P2.54mm_Vertical
J3: pH probe; TerminalBlock_Phoenix_MKDS-1,5-2-5.08_1x02_P5.08mm_Horizont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
J4: ORP probe; TerminalBlock_Phoenix_MKDS-1,5-2-5.08_1x02_P5.08mm_Horizont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
J5: EZO probe; TerminalBlock_Phoenix_MKDS-1,5-2-5.08_1x02_P5.08mm_Horizont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
J6: 1-Wire; TerminalBlock_Phoenix_MKDS-1,5-3-5.08_1x03_P5.08mm_Horizont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
J7: contacts; TerminalBlock_Phoenix_MKDS-1,5-5-5.08_1x05_P5.08mm_Horizont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
J8: 4-20 mA; TerminalBlock_Phoenix_MKDS-1,5-5-5.08_1x05_P5.08mm_Horizont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
J9, J10, J11, J12, J13, J14: EZO socket, top; PinSocket_1x03_P2.54mm_Vertical
J16: Socket; PinSocket_1x04_P2.54mm_Vertical
J17: external; PinHeader_1x04_P2.54mm_Vertical
JP6: one shunt; PinHeader_2x03_P2.54mm_Vertical
R1, R2, R3, R4: 150; R_0805
R5, R6, R7, R8, R9, R10, R11, R12, R26: 1k; R_0805
R13, R14, R15, R16, R29, R30: 10k; R_0805
R17, R18, R19, R20, R21: 100; R_0805
R24, R27, R28: 4.7k; R_0805
R25: 2.2k; R_0805
SW1, SW2: push; SW_Push_1P1T_XKB_TS-1187A

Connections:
+3V3: F1.1, J1.4, J1.5, J1.11
ADC1: C4.1, D1.3, J2.4, R5.2
ADC2: C5.1, D2.3, J1.9, R6.2
ADC3: C6.1, D3.3, J1.7, R7.2
ADC4: C7.1, D4.3, J1.6, R8.2
BTN1: J1.10, J17.1, R29.2, SW1.1
BTN2: J1.12, J17.3, R30.2, SW2.1
DIN1: C8.1, D5.3, J2.9, R9.2
DIN2: C9.1, D6.3, J2.7, R10.2
DIN3: C10.1, D7.3, J2.6, R11.2
DIN4: C11.1, D8.3, J2.5, R12.2
EOR_RX: J1.17, R19.2
EOR_TX: J1.16, R20.2
EPH_RX: J2.20, R17.2
EPH_TX: J2.19, R18.2
EZO_ORP_RX: J9.3, R20.1
EZO_ORP_TX: J9.2, R19.1
EZO_PGND: J5.2, J14.3
EZO_PH_RX: J11.3, R18.1
EZO_PH_TX: J11.2, R17.1
EZO_PRB: J5.1, J14.2
GND: C3.2, C4.2, C5.2, C6.2, C7.2, C8.2, C9.2, C10.2, C11.2, D1.1, D2.1, D3.1, D4.1, D5.1, D6.1, D7.1, D8.1, J1.3, J1.8, J1.13, J1.18, J2.3, J2.8, J2.13, J2.18, J6.3, J7.1, J8.1, J9.1, J11.1, J13.1, J16.1, J17.2, J17.4, R1.2, R2.2, R3.2, R4.2, SW1.2, SW2.2
IN1: J7.2, R9.1, R13.2
IN2: J7.3, R10.1, R14.2
IN3: J7.4, R11.1, R15.2
IN4: J7.5, R12.1, R16.2
ORP_PGND: J4.2, J10.3
ORP_PRB: J4.1, J10.2
OW: J6.2, JP6.2, JP6.4, JP6.6, R21.1
OWGPIO: J2.16, R21.2
PH_PGND: J3.2, J12.3
PH_PRB: J3.1, J12.2
PU10: JP6.5, R26.2
PU22: JP6.3, R25.2
PU47: JP6.1, R24.2
SCL: J1.14, J13.3, J16.3, R28.2
SDA: J1.15, J13.2, J16.4, R27.2
SIG1: J8.2, R1.1, R5.1
SIG2: J8.3, R2.1, R6.1
SIG3: J8.4, R3.1, R7.1
SIG4: J8.5, R4.1, R8.1
V3OUT: C3.1, D1.2, D2.2, D3.2, D4.2, D5.2, D6.2, D7.2, D8.2, F1.2, J6.1, J10.1, J12.1, J14.1, J16.2, R13.1, R14.1, R15.1, R16.1, R24.1, R25.1, R26.1, R27.1, R28.1, R29.1, R30.1

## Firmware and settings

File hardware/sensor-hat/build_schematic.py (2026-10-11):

#!/usr/bin/env python3
"""Schematic for the pool sensor hat. Does not place or route the PCB."""

import math
import re
import uuid
from pathlib import Path

OUT = Path(__file__).resolve().parent
SHEET = str(uuid.uuid5(uuid.NAMESPACE_URL, "pool-sensor-hat-root"))
PROJECT = "sensor-hat"

LIB = {
    "Device:R": "/usr/share/kicad/symbols/Device.kicad_sym",
    "Device:C": "/usr/share/kicad/symbols/Device.kicad_sym",
    "Device:D_Zener": "/usr/share/kicad/symbols/Device.kicad_sym",
    "Device:Polyfuse": "/usr/share/kicad/symbols/Device.kicad_sym",
    "Diode:BAT54S": "/usr/share/kicad/symbols/Diode.kicad_sym",
    "power:GND": "/usr/share/kicad/symbols/power.kicad_sym",
    "power:+3V3": "/usr/share/kicad/symbols/power.kicad_sym",
    "power:PWR_FLAG": "/usr/share/kicad/symbols/power.kicad_sym",
    "Connector_Generic:Conn_01x02": "/usr/share/kicad/symbols/Connector_Generic.kicad_sym",
    "Connector_Generic:Conn_01x03": "/usr/share/kicad/symbols/Connector_Generic.kicad_sym",
    "Connector_Generic:Conn_01x04": "/usr/share/kicad/symbols/Connector_Generic.kicad_sym",
    "Connector_Generic:Conn_01x05": "/usr/share/kicad/symbols/Connector_Generic.kicad_sym",
    "Connector_Generic:Conn_01x20": "/usr/share/kicad/symbols/Connector_Generic.kicad_sym",
    "Connector_Generic:Conn_02x03_Odd_Even": "/usr/share/kicad/symbols/Connector_Generic.kicad_sym",
    "Switch:SW_Push": "/usr/share/kicad/symbols/Switch.kicad_sym",
}

FP_R = "PCM_JLCPCB:R_0805"
FP_C = "PCM_JLCPCB:C_0805"
FP_SOT = "Package_TO_SOT_SMD:SOT-23"
FP_FUSE = "Fuse:Fuse_1812_4532Metric"
FP_JUMP = "Connector_PinHeader_2.54mm:PinHeader_1x02_P2.54mm_Vertical"
FP_JUMP6 = "Connector_PinHeader_2.54mm:PinHeader_2x03_P2.54mm_Vertical"
FP_SOCK = "Connector_PinSocket_2.54mm:PinSocket_1x20_P2.54mm_Vertical"
FP_EZO = "Connector_PinSocket_2.54mm:PinSocket_1x03_P2.54mm_Vertical"
FP_MC = "TerminalBlock_Phoenix:TerminalBlock_Phoenix_MKDS-1,5_{n}-5.08_1x0{n}_P5.08mm_Horizontal"

LCSC = {
    "150": "C17471",
    "1k": "C17513",
    "10k": "C17414",
    "4.7k": "C17673",
    "2.2k": "C17520",
    "100": "C17408",
    "100n": "C28233",
    "10u": "C15850",
    "BAT54S": "C7420333",
}


def uid():
    return str(uuid.uuid4())


def snap(value):
    """KiCad's schematic connection grid is 1.27 mm."""
    return round(round(value / 1.27) * 1.27, 2)


def extract_symbol(path, name):
    text = Path(path).read_text(errors="replace")
    token = f'(symbol "{name}"'
    i = text.find(token)
    if i < 0:
        raise SystemExit(f"missing symbol {name} in {path}")
    depth = 0
    for j, ch in enumerate(text[i:], i):
        if ch == "(":
            depth += 1
        elif ch == ")":
            depth -= 1
            if depth == 0:
                return text[i : j + 1]
    raise SystemExit(f"unbalanced {name}")


def unit_pins(block):
    import re

    m = re.search(r'\(symbol "[^"]+_1_1"', block)
    if not m:
        sub = block
    else:
        start = m.start()
        depth = 0
        for j, ch in enumerate(block[start:], start):
            if ch == "(":
                depth += 1
            elif ch == ")":
                depth -= 1
                if depth == 0:
                    sub = block[start : j + 1]
                    break
    pins = {}
    i = 0
    while True:
        k = sub.find("(pin ", i)
        if k < 0:
            break
        depth = 0
        for j, ch in enumerate(sub[k:], k):
            if ch == "(":
                depth += 1
            elif ch == ")":
                depth -= 1
                if depth == 0:
                    pin = sub[k : j + 1]
                    break
        at = re.search(r"\(at ([-\d.]+) ([-\d.]+) (\d+)\)", pin)
        num = re.search(r'\(number "([^"]*)"', pin)
        pins[num.group(1)] = (float(at.group(1)), float(at.group(2)), int(at.group(3)))
        i = j + 1
    return pins


def rename_symbol(block, lib_id):
    name = lib_id.split(":", 1)[1]
    old = f'(symbol "{name}"'
    new = f'(symbol "{lib_id}"'
    if not block.startswith(old):
        raise SystemExit(f"rename failed for {lib_id}")
    return new + block[len(old) :]


def rename_pins(block, names):
    for i, label in enumerate(names, start=1):
        old = f'(name "Pin_{i}"'
        new = f'(name "{label}"'
        if old not in block:
            raise SystemExit(f"missing {old}")
        block = block.replace(old, new, 1)
    return block


class Sch:
    def __init__(self):
        self.raw_syms = {}
        self.pins = {}
        self.parts = []
        self.wires = []
        self.labels = []
        self.ncs = []
        self.texts = []
        self.bom = []
        self.pwr = 0
        self.flg = 0
        for lib_id, path in LIB.items():
            name = lib_id.split(":", 1)[1]
            block = extract_symbol(path, name)
            self.pins[lib_id] = unit_pins(block)
            self.raw_syms[lib_id] = rename_symbol(block, lib_id)
        v3 = self.raw_syms["power:+3V3"].replace("+3V3", "V3OUT")
        self.raw_syms["power:V3OUT"] = v3
        self.pins["power:V3OUT"] = dict(self.pins["power:+3V3"])

    def clone_symbol(self, src, lib_id, pin_names, pin_at=None):
        sym_name = lib_id.split(":", 1)[1]
        src_name = src.split(":", 1)[1]
        block = self.raw_syms[src]
        block = block.replace(f'(symbol "{src}"', f'(symbol "{lib_id}"', 1)
        block = block.replace(f'(symbol "{src_name}_', f'(symbol "{sym_name}_')
        block = rename_pins(block, pin_names)
        block = re.sub(
            r"\(pin_names(\s*)\(offset 1\.016\)(\s*)\(hide yes\)",
            r"(pin_names\1(offset 1.016)\2(hide no)",
            block,
            count=1,
        )
        def at_text(coords):
            parts = []
            for value in coords:
                number = float(value)
                parts.append(str(int(number)) if number == int(number) else str(number))
            return "(at " + " ".join(parts) + ")"

        pins = {num: coords for num, coords in self.pins[src].items()}
        if pin_at:
            for num, at in pin_at.items():
                old = at_text(pins[num])
                new = at_text(at)
                if old not in block:
                    raise SystemExit(f"missing {old} in {lib_id}")
                block = block.replace(old, new, 1)
                pins[num] = at
        self.raw_syms[lib_id] = block
        self.pins[lib_id] = pins

    def custom_header(self, lib_id, names):
        sym_name = lib_id.split(":", 1)[1]
        block = rename_pins(self.raw_syms["Connector_Generic:Conn_01x20"], names)
        block = block.replace('(symbol "Connector_Generic:Conn_01x20"', f'(symbol "{lib_id}"', 1)
        block = block.replace('(symbol "Conn_01x20_', f'(symbol "{sym_name}_')
        block = re.sub(
            r"\(pin_names(\s*)\(offset 1\.016\)(\s*)\(hide yes\)",
            r"(pin_names\1(offset 1.016)\2(hide no)",
            block,
            count=1,
        )
        self.raw_syms[lib_id] = block
        self.pins[lib_id] = self.pins["Connector_Generic:Conn_01x20"]

    def add_box(self, lib_id, title, right, left=(), width=50.8):
        """One schematic block. right and left are (name, sheet_dy) from the top pin.

        sheet_dy is 0 at the top pin and negative below it. Pins land on the
        right and left edges. The placed symbol origin is the top right pin.
        """
        sym = lib_id.split(":", 1)[1]
        pins = {}
        chunks = []
        number = 1
        lib_ys = []

        def add_pin(name, sheet_dy, x, angle, num):
            lib_y = -sheet_dy
            lib_ys.append(lib_y)
            pins[str(num)] = (x, lib_y, angle)
            chunks.append(
                "\t\t(pin passive line\n"
                f"\t\t\t(at {x} {lib_y} {angle})\n"
                "\t\t\t(length 2.54)\n"
                f'\t\t\t(name "{name}"\n'
                "\t\t\t\t(effects (font (size 1.27 1.27)))\n"
                "\t\t\t)\n"
                f'\t\t\t(number "{num}"\n'
                "\t\t\t\t(effects (font (size 1.27 1.27)))\n"
                "\t\t\t)\n"
                "\t\t)"
            )

        def walk(entries, x, angle):
            nonlocal number
            for entry in entries:
                if len(entry) == 3:
                    name, sheet_dy, num = entry
                else:
                    name, sheet_dy = entry
                    num = number
                    number += 1
                add_pin(name, sheet_dy, x, angle, num)

        walk(right, 0, 180)
        walk(left, -width, 0)
        top = min(lib_ys) - 5.08
        bot = max(lib_ys) + 5.08
        body = (
            f'\t\t(rectangle (start {-width} {top}) (end -2.54 {bot})\n'
            "\t\t\t(stroke (width 0.254) (type default))\n"
            "\t\t\t(fill (type background)))\n"
            f'\t\t(text "{title}" (at {-width / 2} {top + 2.54} 0)\n'
            "\t\t\t(effects (font (size 1.27 1.27))))"
        )
        block = (
            f'(symbol "{lib_id}"\n'
            "\t(pin_numbers (hide yes))\n"
            "\t(pin_names (offset 1.016))\n"
            "\t(exclude_from_sim no)\n"
            "\t(in_bom no)\n"
            "\t(on_board no)\n"
            f'\t(property "Reference" "U" (at {-width / 2} {top - 2.54} 0)\n'
            "\t\t(effects (font (size 1.27 1.27))))\n"
            f'\t(property "Value" "{title}" (at {-width / 2} {bot + 2.54} 0)\n'
            "\t\t(effects (font (size 1.27 1.27))))\n"
            '\t(property "Footprint" "" (at 0 0 0)\n'
            "\t\t(effects (font (size 1.27 1.27)) (hide yes)))\n"
            '\t(property "Datasheet" "" (at 0 0 0)\n'
            "\t\t(effects (font (size 1.27 1.27)) (hide yes)))\n"
            f'\t(symbol "{sym}_0_1"\n{body}\n\t)\n'
            f'\t(symbol "{sym}_1_1"\n' + "\n".join(chunks) + "\n\t)\n"
            "\t(embedded_fonts no)\n"
            ")"
        )
        self.raw_syms[lib_id] = block
        self.pins[lib_id] = pins

    def place(self, lib_id, ref, value, x, y, footprint="", extra=None, rot=0, bom=True, dnp=False):
        # A placed symbol mirrors the library Y axis, then rotates.
        x, y = snap(x), snap(y)
        extra = dict(extra or {})
        ref_at = extra.pop("ref_at", None)
        val_at = extra.pop("val_at", None)
        world = {}
        rad = math.radians(rot)
        c, s = math.cos(rad), math.sin(rad)
        for num, (px, py, ang) in self.pins[lib_id].items():
            lx, ly = px, -py
            rx = lx * c - ly * s
            ry = lx * s + ly * c
            vx = math.cos(math.radians(ang))
            vy = -math.sin(math.radians(ang))
            wx = vx * c - vy * s
            wy = vx * s + vy * c
            world_ang = round(math.degrees(math.atan2(wy, wx))) % 360
            world[num] = (round(x + rx, 2), round(y + ry, 2), world_ang)
        self.parts.append(
            {
                "lib_id": lib_id,
                "ref": ref,
                "value": value,
                "footprint": footprint,
                "x": x,
                "y": y,
                "rot": rot,
                "extra": extra,
                "pins": world,
                "bom": bom,
                "dnp": dnp,
                "ref_at": ref_at,
                "val_at": val_at,
            }
        )
        if bom and not dnp and not ref.startswith("#"):
            lcsc = (extra or {}).get("LCSC", "")
            self.bom.append((ref, value, footprint, lcsc))
        return world

    def wire(self, x1, y1, x2, y2):
        x1, y1, x2, y2 = (round(v, 2) for v in (x1, y1, x2, y2))
        if (x1, y1) != (x2, y2):
            self.wires.append((x1, y1, x2, y2))

    def stub(self, x, y, ang, length=5.08):
        rad = math.radians(ang + 180)
        x2 = round(x + length * math.cos(rad), 2)
        y2 = round(y + length * math.sin(rad), 2)
        self.wire(x, y, x2, y2)
        return x2, y2

    def label(self, name, x, y, grow="right"):
        self.labels.append((name, round(x, 2), round(y, 2), grow))

    def nc(self, x, y):
        self.ncs.append((round(x, 2), round(y, 2)))

    def text(self, body, x, y, size=1.27):
        self.texts.append((body, round(x, 2), round(y, 2), size))

    def tie(self, pin, net, length=5.08):
        x, y, ang = pin
        ex, ey = self.stub(x, y, ang, length)
        if net == "GND":
            self.pwr += 1
            self.place("power:GND", f"#PWR{self.pwr:03d}", "GND", ex, ey, bom=False)
        elif net in ("+3V3", "V3OUT"):
            self.pwr += 1
            self.place(f"power:{net}", f"#PWR{self.pwr:03d}", net, ex, ey, bom=False)
        else:
            grow = "left" if math.cos(math.radians(ang + 180)) < 0 else "right"
            self.label(net, ex, ey, grow)
        return ex, ey

    def flag(self, x, y):
        self.flg += 1
        self.place("power:PWR_FLAG", f"#FLG{self.flg:02d}", "PWR_FLAG", x, y, bom=False)

    def emit(self, path):
        L = []
        w = L.append
        w("(kicad_sch")
        w("\t(version 20250114)")
        w('\t(generator "eeschema")')
        w('\t(generator_version "9.0")')
        w(f'\t(uuid "{SHEET}")')
        w('\t(paper "A1")')
        w("\t(title_block")
        w('\t\t(title "Pool sensor hat")')
        w('\t\t(date "2026-10-06")')
        w('\t\t(rev "1")')
        w('\t\t(company "Pool-Controller")')
        w('\t\t(comment 1 "P1 is J1 and J2, the two Pico sockets, one Waveshare interface.")')
        w('\t\t(comment 2 "U1, U2, and U3 are the plug-in EZO boards. PGND is not GND.")')
        w('\t\t(comment 3 "Signal nets are wired. Power and ground use symbols.")')
        w('\t\t(comment 4 "J1 pins 4 and 5 are 3.3 V on the Waveshare and are open on this hat.")')
        w("\t)")
        w("\t(lib_symbols")
        for lib_id, block in self.raw_syms.items():
            for line in block.splitlines():
                w("\t" + line)
        w("\t)")
        for part in self.parts:
            self._emit_part(w, part)
        for x1, y1, x2, y2 in self.wires:
            w("\t(wire")
            w("\t\t(pts")
            w(f"\t\t\t(xy {x1} {y1})")
            w(f"\t\t\t(xy {x2} {y2})")
            w("\t\t)")
            w("\t\t(stroke (width 0) (type solid))")
            w(f'\t\t(uuid "{uid()}")')
            w("\t)")
        for name, x, y, grow in self.labels:
            just = "right" if grow == "left" else "left"
            w("\t(label " + _q(name))
            w(f"\t\t(at {x} {y} 0)")
            w("\t\t(effects (font (size 1.27 1.27)) (justify " + just + " bottom))")
            w(f'\t\t(uuid "{uid()}")')
            w("\t)")
        for x, y in self.ncs:
            w("\t(no_connect")
            w(f"\t\t(at {x} {y})")
            w(f'\t\t(uuid "{uid()}")')
            w("\t)")
        for body, x, y, size in self.texts:
            w("\t(text " + _q(body))
            w("\t\t(exclude_from_sim no)")
            w(f"\t\t(at {x} {y} 0)")
            w("\t\t(effects (font (size " + f"{size} {size}" + ")))")
            w(f'\t\t(uuid "{uid()}")')
            w("\t)")
        w("\t(sheet_instances")
        w('\t\t(path "/"')
        w('\t\t\t(page "1")')
        w("\t\t)")
        w("\t)")
        w("\t(embedded_fonts no)")
        w(")")
        path.write_text("\n".join(L) + "\n")

    def _emit_part(self, w, part):
        x, y = part["x"], part["y"]
        power = part["lib_id"].startswith("power:")
        fitted = part["bom"] and not part.get("dnp")
        on_board = "yes" if part["bom"] or part.get("dnp") else "no"
        in_bom = "yes" if fitted else "no"
        w("\t(symbol")
        w(f'\t\t(lib_id "{part["lib_id"]}")')
        w(f'\t\t(at {x} {y} {part["rot"]})')
        w("\t\t(unit 1)")
        w("\t\t(exclude_from_sim no)")
        w(f'\t\t(in_bom {in_bom})')
        w(f'\t\t(on_board {on_board})')
        w(f'\t\t(dnp {"yes" if part.get("dnp") else "no"})')
        w(f'\t\t(uuid "{uid()}")')
        ref_at = part["ref_at"] or (x + 6.35, y + 3.81)
        val_at = part["val_at"] or (x + 6.35, y - 3.81)
        fields = [
            ("Reference", part["ref"], ref_at[0], ref_at[1], power),
            ("Value", part["value"], val_at[0], val_at[1], False),
            ("Footprint", part["footprint"], x, y, True),
            ("Datasheet", part["extra"].get("Datasheet", ""), x, y, True),
        ]
        for key, val in part["extra"].items():
            if key in ("Reference", "Value", "Footprint", "Datasheet"):
                continue
            fields.append((key, val, x, y, True))
        for key, val, px, py, hide in fields:
            w(f"\t\t(property \"{key}\" {_q(val)}")
            w(f"\t\t\t(at {px} {py} 0)")
            if hide:
                w("\t\t\t(effects (font (size 1.27 1.27)) (hide yes))")
            else:
                w("\t\t\t(effects (font (size 1.27 1.27)))")
            w("\t\t)")
        for num in part["pins"]:
            w(f'\t\t(pin "{num}"')
            w(f'\t\t\t(uuid "{uid()}")')
            w("\t\t)")
        w("\t\t(instances")
        w(f'\t\t\t(project "{PROJECT}"')
        w(f'\t\t\t\t(path "/{SHEET}"')
        w(f'\t\t\t\t\t(reference "{part["ref"]}")')
        w("\t\t\t\t\t(unit 1)")
        w("\t\t\t\t)")
        w("\t\t\t)")
        w("\t\t)")
        w("\t)")


def _q(text):
    return '"' + str(text).replace("\\", "\\\\").replace('"', '\\"') + '"'


PITCH = 15.24
GAP = 30.48
TOP = 40.0


def r_extra(value):
    return {"LCSC": LCSC[value], "Tolerance": "1%"}
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

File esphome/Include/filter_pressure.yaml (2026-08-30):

# Filter tank head-pressure package
#
# Hardware: 2-wire 4-20mA silicon pressure transmitter (Yosoo 0-0.5 MPa / G1/4,
# Amazon B07NQ36XTC or equivalent) on the Waveshare ESP32-S3-RELAY-6CH Pico header.
#
# Clean baselines are learned per Speed 1–4: the lowest N-hour average while
# the pump holds that speed (N = Filter Learn Hours, default 2). Unsaved speeds
# are estimated from learned points using head ≈ a + b·RPM².
# Triton II trip: +10 psi. See esphome/FILTER_PRESSURE.md.

web_server:
  sorting_groups:
    - id: sorting_group_filter
      name: "Filter Pressure"
      sorting_weight: -8

globals:
  - id: g_filter_needs_backwash
    type: bool
    restore_value: yes
    initial_value: "false"
  - id: g_filter_learn_clear
    type: int
    restore_value: no
    initial_value: "-1"
  - id: g_filter_learn_hours
    type: float
    restore_value: no
    initial_value: "0"
  - id: g_filter_learn_speed
    type: int
    restore_value: no
    initial_value: "0"

number:
  - platform: template
    name: "Filter Clean Speed 1"
    id: filter_clean_speed1_psi
    min_value: 0
    max_value: 50
    step: 0.5
    unit_of_measurement: "psi"
    optimistic: true
    restore_value: true
    initial_value: 0
    mode: box
    icon: "mdi:numeric-1"
    entity_category: config
    web_server:
      sorting_group_id: sorting_group_filter
      sorting_weight: 10
    on_value:
      then:
        - script.execute: filter_recalc

  - platform: template
    name: "Filter Clean Speed 2"
    id: filter_clean_speed2_psi
    min_value: 0
    max_value: 50
    step: 0.5
    unit_of_measurement: "psi"
    optimistic: true
    restore_value: true
    initial_value: 0
    mode: box
    icon: "mdi:numeric-2"
    entity_category: config
    web_server:
      sorting_group_id: sorting_group_filter
      sorting_weight: 11
    on_value:
      then:
        - script.execute: filter_recalc

  - platform: template
    name: "Filter Clean Speed 3"
    id: filter_clean_speed3_psi
    min_value: 0
    max_value: 50
    step: 0.5
    unit_of_measurement: "psi"
    optimistic: true
    restore_value: true
    initial_value: 0
    mode: box
    icon: "mdi:numeric-3"
    entity_category: config
    web_server:
      sorting_group_id: sorting_group_filter
      sorting_weight: 12
    on_value:
      then:
        - script.execute: filter_recalc

  - platform: template
    name: "Filter Clean Speed 4"
    id: filter_clean_speed4_psi
    min_value: 0
    max_value: 50
    step: 0.5
    unit_of_measurement: "psi"
    optimistic: true
    restore_value: true
    initial_value: 0
    mode: box
    icon: "mdi:numeric-4"
    entity_category: config
    web_server:
      sorting_group_id: sorting_group_filter
      sorting_weight: 13
    on_value:
      then:
        - script.execute: filter_recalc

  - platform: template
    name: "Filter Learn Hours"
    id: filter_learn_hours
    min_value: 1
    max_value: 48
    step: 1
    unit_of_measurement: "h"
    optimistic: true
    restore_value: true
    initial_value: 2
    mode: box
    icon: "mdi:timer-sand"
    entity_category: config
    web_server:
      sorting_group_id: sorting_group_filter
      sorting_weight: 20
    on_value:
      then:
        - lambda: id(g_filter_learn_clear) = 99;
        - script.execute: filter_recalc

  - platform: template
    name: "Filter Pressure Rise"
    id: filter_pressure_rise_psi
    min_value: 2
    max_value: 25
    step: 0.5
    unit_of_measurement: "psi"
    optimistic: true
    restore_value: true
    initial_value: 10
    mode: box
    icon: "mdi:arrow-up-bold"
    entity_category: config
    web_server:
      sorting_group_id: sorting_group_filter
      sorting_weight: 14
    on_value:
      then:
        - script.execute: filter_recalc
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

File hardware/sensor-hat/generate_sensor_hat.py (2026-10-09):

#!/usr/bin/env python3
"""Generate the pool sensor hat KiCad board, schematic, BOM, and a placement preview.

Coordinates are millimetres, KiCad style: X to the right, Y up.
Mounted orientation: Y-up is the Waveshare USB side, X-right is the antenna side.
The female socket is on the bottom, against the top edge, right of center.
It is a Pico socket: two 1x20 rows, 2.54 mm along each row, 17.78 mm between rows.
A Raspberry Pi 40-pin GPIO header is 2.54 mm between rows and is not this footprint.
"""

import heapq
import math
import time
import uuid
from collections import defaultdict
from pathlib import Path

OUT = Path(__file__).resolve().parent

BOARD_W = 132.0
BOARD_H = 70.0
# Pin 40 / pin 1 (antenna, 5 V end) pin-center.
RIGHT_X = 116.0
TOP_Y = 65.2
# Pico row spacing is 0.7 in. A Pi GPIO 2x20 header is one pitch, 2.54 mm.
ROW_GAP = 17.78
BOT_Y = TOP_Y - ROW_GAP
PITCH = 2.54

# Clearances and sizes.
SIG_W = 0.25
PWR_W = 0.50
GND_W = 0.40
VIA_OD = 0.80
VIA_DR = 0.40
PAD_HDR = 1.70
DRILL_HDR = 1.00
PAD_TERM = 2.40
DRILL_TERM = 1.40
CLEAR = 0.20


def uid():
    return str(uuid.uuid4())


def px(idx):
    """X of header column idx, 0 at the antenna end."""
    return RIGHT_X - idx * PITCH


def dist_point_seg(px_, py, x1, y1, x2, y2):
    dx, dy = x2 - x1, y2 - y1
    L2 = dx * dx + dy * dy
    if L2 == 0:
        return math.hypot(px_ - x1, py - y1)
    t = max(0.0, min(1.0, ((px_ - x1) * dx + (py - y1) * dy) / L2))
    return math.hypot(px_ - (x1 + t * dx), py - (y1 + t * dy))


def _orient(p, q, r):
    return (q[0] - p[0]) * (r[1] - p[1]) - (q[1] - p[1]) * (r[0] - p[0])


def _on_seg(a, b, p):
    return (
        min(a[0], b[0]) - 1e-6 <= p[0] <= max(a[0], b[0]) + 1e-6
        and min(a[1], b[1]) - 1e-6 <= p[1] <= max(a[1], b[1]) + 1e-6
    )


def _segs_intersect(a, b, c, d):
    o1, o2 = _orient(a, b, c), _orient(a, b, d)
    o3, o4 = _orient(c, d, a), _orient(c, d, b)
    if o1 * o2 < 0 and o3 * o4 < 0:
        return True
    if abs(o1) < 1e-9 and _on_seg(a, b, c):
        return True
    if abs(o2) < 1e-9 and _on_seg(a, b, d):
        return True
    if abs(o3) < 1e-9 and _on_seg(c, d, a):
        return True
    if abs(o4) < 1e-9 and _on_seg(c, d, b):
        return True
    return False


def seg_seg_dist(a, b, c, d):
    # Non-crossing segments are closest at an endpoint.
    if _segs_intersect(a, b, c, d):
        return 0.0
    return min(
        dist_point_seg(a[0], a[1], c[0], c[1], d[0], d[1]),
        dist_point_seg(b[0], b[1], c[0], c[1], d[0], d[1]),
        dist_point_seg(c[0], c[1], a[0], a[1], b[0], b[1]),
        dist_point_seg(d[0], d[1], a[0], a[1], b[0], b[1]),
    )


class Board:
    def __init__(self):
        self.nets = {"": 0}
        self.pads = []  # dicts
        self.tracks = []
        self.vias = []
        self.graphics = []  # gr_line / gr_text / fp graphics stored as tuples
        self.footprints = []
        self.bom = []

    def net(self, name):
        if name not in self.nets:
            self.nets[name] = len(self.nets)
        return self.nets[name]

    def add_fp(self, ref, value, layer, at, pads, lines, texts):
        self.footprints.append(
            {
                "ref": ref,
                "value": value,
                "layer": layer,
                "at": at,
                "rot": 0,
                "pads": pads,
                "lines": lines,
                "texts": texts,
            }
        )
        for p in pads:
            rec = dict(p)
            rec["ref"] = ref
            if rec["net"]:
                self.net(rec["net"])
            self.pads.append(rec)

    def track(self, net, x1, y1, x2, y2, layer, width):
        if abs(x1 - x2) < 1e-6 and abs(y1 - y2) < 1e-6:
            return
        self.net(net)
        self.tracks.append(
            {"net": net, "x1": x1, "y1": y1, "x2": x2, "y2": y2, "layer": layer, "w": width}
        )

    def ortho(self, net, pts, layer, width):
        """Route an orthogonal polyline. pts are (x, y). Inserts a corner if needed."""
        if len(pts) < 2:
            return
        seq = [pts[0]]
        for x, y in pts[1:]:
            px_, py = seq[-1]
            if abs(px_ - x) > 1e-6 and abs(py - y) > 1e-6:
                seq.append((x, py))
            seq.append((x, y))
        for (x1, y1), (x2, y2) in zip(seq, seq[1:]):
            self.track(net, x1, y1, x2, y2, layer, width)

    def via(self, net, x, y):
        self.net(net)
        self.vias.append({"net": net, "x": x, "y": y})

    def silk(self, text, x, y, layer="F.SilkS", size=1.0, rot=0):
        self.graphics.append(("text", text, x, y, layer, size, rot))

    def line(self, x1, y1, x2, y2, layer, width=0.12):
        self.graphics.append(("line", x1, y1, x2, y2, layer, width))

    def rect(self, x1, y1, x2, y2, layer, width=0.12):
        self.line(x1, y1, x2, y1, layer, width)
        self.line(x2, y1, x2, y2, layer, width)
        self.line(x2, y2, x1, y2, layer, width)
        self.line(x1, y2, x1, y1, layer, width)
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

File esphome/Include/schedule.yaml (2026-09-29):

# pentair_if_ic is loaded by the parent yaml (local ../components or GitHub).

esphome:
  on_boot:
    - priority: -100
      then:
        - delay: 5s
        - script.execute: refresh_speed_labels

uart:
  - id: uart_bus
    tx_pin: ${pentair_tx_pin}
    rx_pin: ${pentair_rx_pin}
    baud_rate: 9600

pentair_if_ic:
  id: my_pentair
  uart_id: uart_bus
  # CircuPool RJ-60 PLUS is not IntelliChlor. Leave false or the ESP polls a
  # missing SWG and logs "IC No response ... removing from send queue".
  # Set true only if you uncomment Include/chlorinator.yaml for a Pentair SWG.
  enable_intellichlor: false

binary_sensor:
  # pump running state from pump
  - platform: pentair_if_ic
    running:
      name: "Pump Running"
      id: pump_running

  # pump running status copied from pump
  - platform: copy
    source_id: pump_running
    name: "Pump Status"
    id: pump_running_status
    icon: "mdi:pump"
    internal: true
    on_state:
      then:
        - lambda: |-
            if (id(pump_running).state == true) {
              id(g_pump_started_running_millis) = millis();
            }
            else {
              id(g_pump_stopped_running_millis) = millis();
            }
    web_server:
      sorting_group_id: sorting_group_pump_status
      sorting_weight: 2

# Enable web server for direct access
web_server:
  port: 80
  version: 3
  ota: false
  sorting_groups:
    - id: schedule1
      name: "Schedule 1"
      sorting_weight: -19
    - id: schedule2
      name: "Schedule 2"
      sorting_weight: -18
    - id: schedule3
      name: "Schedule 3"
      sorting_weight: -17
    - id: schedule4
      name: "Schedule 4"
      sorting_weight: -16
    - id: pump_end
      name: "Pump End"
      sorting_weight: -14
    - id: pump_speeds
      name: "Pump Speeds"
      sorting_weight: -13
    - id: sorting_group_pump_status
      name: "Pump Status"
      sorting_weight: -20
    - id: sorting_group_light
      name: "Light"
      sorting_weight: -4

# Time component for scheduling
time:
  - platform: homeassistant
    id: homeassistant_time
    timezone: America/New_York # Change to your timezone

button:
  - platform: template
    name: "Sync Pump Clock"
    internal: true
    on_press:
      then:
        - lambda: |-
            auto time = id(homeassistant_time).now();
            id(my_pentair).setPumpClock(time.hour, time.minute);
  
  - platform: template
    name: "Request Pump Status"
    internal: true
    on_press:
      - lambda: id(my_pentair).requestPumpStatus();
  
  - platform: template
    name: "Pump Run"
    id: pump_run
    icon: "mdi:play"
    on_press:
      - lambda: |-
          // Start at the last Speed 1–4 sent to the pump. Do not restore Auto:
          // Auto only enables the clock, and a speed switch that is already
          // "on" skips commandRPM. Reselecting a speed in Mode works because
          // that path always sends RPM and turns Auto off.
          int n = id(g_last_speed_n);
          if (n < 1 || n > 4) {
            auto starts = [](const std::string &s, const char *p) -> bool {
              return s.rfind(p, 0) == 0;
            };
            const std::string last = id(g_last_pump_mode);
            if (starts(last, "Speed 2")) n = 2;
            else if (starts(last, "Speed 3")) n = 3;
            else if (starts(last, "Speed 4")) n = 4;
            else n = 1;
          }
          id(g_last_speed_n) = n;
          id(g_last_pump_mode) = n == 1 ? "Speed 1" : n == 2 ? "Speed 2" : n == 3 ? "Speed 3" : "Speed 4";

          const std::string option =
              n == 1 ? id(g_label_s1) : n == 2 ? id(g_label_s2) : n == 3 ? id(g_label_s3) : id(g_label_s4);
          const float rpm =
              n == 1 ? id(pump_speed_1).state : n == 2 ? id(pump_speed_2).state : n == 3 ? id(pump_speed_3).state : id(pump_speed_4).state;
          ESP_LOGI("pump", "Pump Run: Speed %d (%.0f RPM)", n, rpm);

          id(auto_schedule_switch).turn_off();
          id(g_refreshing_speed_labels) = true;
          id(manual_override_select).publish_state(option);
          id(g_refreshing_speed_labels) = false;
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

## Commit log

2026-08-30 Add filter-tank 4-20mA pressure sensing and a one-file HA ESPHome config.
    [ha-pool-controller.yaml, pool-controller.yaml]
2026-08-30 Add Atlas pH/Stenner dosing, per-speed filter learn, and drop unused dashboard tools. Changelog: - Stenner 45M5 acid pulses on CH2 with pump/RPM/pH/daily-cap interlocks - Atlas Industrial pH Kit (KIT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
    [ha-pool-controller.yaml, pool-controller.yaml]
2026-08-30 Fix template switch restore_mode for current ESPHome. Acid Auto Dose and Waterfall Auto used restore_value, which is no longer valid on switch.template.
    [acid_ph.yaml, schedule.yaml]
2026-08-30 Report air and water temperature in Fahrenheit only. Convert DS18B20 readings on the device and drop the extra C/_F entities so HA and web_server stay in °F.
2026-08-30 Hide unused waterfall, duplicate, and debug entities from HA and the device page. Keep the logic (ADC loops, CH1 off, schedule waterfall flags) but mark those sensors internal so this pad only shows 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
    [pool-controller.yaml]
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2026-08-31 Stop IntelliChlor RS485 polling on this CircuPool install. Commenting out chlorinator.yaml only hid entities; the driver still queued IC packets and logged "IC No response". Add enable_intellichlor a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
    [ha-pool-controller.yaml, pool-controller.yaml]
2026-09-09 Expose Pool pH to Home Assistant as a polled sensor and trim the Atlas 4–20 mA reading down by 0.2 so ESP/HA match the transmitter display.
    [ha-pool-controller.yaml, pool-controller.yaml]
2026-09-09 Add 0.2 pH to the Atlas loop reading, drop '/' from entity names before ESPHome 2027.7, and ignore the GPIO46 strapping warning on the hardwired light relay.
    [ha-pool-controller.yaml, pool-controller.yaml]
2026-09-09 Use 100 RPM steps on the pump speed sliders so the ESP web page is easier to set.
2026-09-09 Remove Pump Speed 5 from the firmware. Speeds 1–4 remain, with 100 RPM slider steps.
2026-09-09 Stop blocking acid dosing on filter pressure fault. Backwash remains a status-only flag.
2026-09-09 Stop releasing the IntelliFlo to local control on every status poll so the ESP can keep managing the pump after a reboot.
2026-09-09 Resume the last Auto or Speed 1–4 setting when Pump Run is pressed from Off.
2026-09-09 Show each pump speed’s RPM in the Mode and schedule dropdowns in Home Assistant and on the ESP page.
2026-09-09 Add ph_update_interval so the Home Assistant YAML can set how often the pH ADC and Pool pH sensors poll.
    [ha-pool-controller.yaml, pool-controller.yaml]
2026-09-09 Fix Acid Interlock settle countdown snprintf types for ESP32 uint32_t.
    [acid_ph.yaml]
2026-09-09 Expose Stenner acid volume to Home Assistant from pump runtime at 25 GPD.
    [ha-pool-controller.yaml, pool-controller.yaml]
2026-09-10 Stop sending Pump Clock Formatted to Home Assistant every minute.
2026-09-20 Fix Pump Stop hanging the ESP, and actually stop after pump end time. Publishing Mode Off from the Off switch retriggered on_value in a tight stop() loop. After 22:00 the schedule only cleared speed 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
    [schedule.yaml]
2026-09-20 Color ESP device logs by who is talking. Yellow is ESP→pump, cyan is pump→ESP, and sensors/schedule use their own colors so TX, RX, and readings are easy to tell apart in ESPHome Builder.
    [ha-pool-controller.yaml, pool-controller.yaml]
2026-09-20 Drop the OTA password and reuse the API encryption key. ESPHome 2026.9 flags password: when the device already has api encryption; a bare ota encryption: block inherits that key and clears the Device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
    [ha-pool-controller.yaml, pool-controller.yaml]
2026-09-20 Disable web_server OTA so encrypted ESPHome OTA is the only update path.
    [ha-pool-controller.yaml, pool-controller.yaml]
2026-09-20 Drop ANSI log colors; tag TX and RX instead. ESPHome Builder prints color codes as garbage, so speakers are identified with if.tx / if.rx tags.
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2026-09-28 Post pool pH and water temperature to PoolVera once an hour.
    [ha-pool-controller.yaml, pool-controller.yaml]
2026-09-28 Add a Sync to the Cloud button for an immediate PoolVera reading.
2026-09-28 Show Sync to the Cloud under Temperature and always pull the latest firmware.
    [ha-pool-controller.yaml]
2026-09-28 Put the PoolVera sync button in the Home Assistant device YAML.
    [ha-pool-controller.yaml, pool-controller.yaml]
2026-09-28 Let the controller secret be the device key shown on the pool Settings page.
    [ha-pool-controller.yaml, pool-controller.yaml]
2026-09-29 Rename the controller section to PoolVeras and post to poolveras.com.
    [ha-pool-controller.yaml, pool-controller.yaml]
2026-09-29 Rename controller ids, tags, and the secret to poolveras.
    [ha-pool-controller.yaml, pool-controller.yaml]
2026-09-29 Make Pump Run start the last Speed 1-4 instead of restoring Auto.
2026-09-29 Give the PoolVeras clock strings room so the ESP-IDF build accepts snprintf.
    [ha-pool-controller.yaml]
2026-09-29 Load PoolVeras from GitHub and format the clock without snprintf.
    The ESP-IDF build treats the small date buffer in the Home Assistant device file as an error, and that file is not updated by a package refresh.
    [ha-pool-controller.yaml]
2026-10-09 Add the sensor hat and map the controller firmware onto it.
    PoolverasV1 needs the board and the pin map so the new hardware can be built while the legacy controller stays where it is.
    [bom.csv, ha-pool-controller.yaml, pool-controller.yaml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]
2026-10-09 Describe the sensor hat and publish the ESP chip temperature.
    The old Pico pin notes no longer match the hat, and the chip temperature was not in the device config.
2026-10-09 Summarize the hat and the Waveshare on the GitHub README.
    The repo page should say what this controller is for and how the two boards divide the work.
2026-10-10 Lay out the PoolVeras V1.1 hat with the display, Atlas boards, and two buttons.
    Socket 3 stays on the display I2C bus, and the screen shows pH, ORP, and water temperature.
    [Atlas_EZO_EZO.step, Atlas_EZO_ORP.step, Atlas_EZO_pH.step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]
2026-10-11 Record the hat after the display, button, and routing passes.
    The board now keeps the packed Atlas modules, the external switch header, and the shorter front-side wiring.
    [bom.csv, sensor-hat.kicad_pcb, sensor-hat.kicad_sch]
2026-10-11 Match the controller to the finished hat pinout and the 1-Wire slide switch.
2026-10-11 Read filter pressure from the analog pin on J8 screw 1, and keep the Waveshare pinout in the repo.
2026-10-13 Show Poolveras on the display while button A is held, and put orderable part numbers on the hat BOM.
